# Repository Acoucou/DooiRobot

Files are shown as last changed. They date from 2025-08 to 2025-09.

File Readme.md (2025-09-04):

# DooiRobot

## 概述

该项目由doly魔改而来，3D模型做了适配，硬件以及软件为自制，采用聆思的CSK6；

请用 “嘿、dooi” 唤醒我

当前支持功能如下：

1、单轮多轮对话，打断唤醒

2、支持情绪理解，多种情感反馈（眼睛、led、舵机、电机的结合）

3、支持物体识别、拍照等

4、支持音乐播放

5、支持蓝牙配网，局域网web控制

6、

- [视频演示]()
- 

## 固件烧录

1、[下载烧录软件](https://docs2.listenai.com/zz/6941.exe?shortId=oo2_KzYFd)

2、将bin固件拖至软件

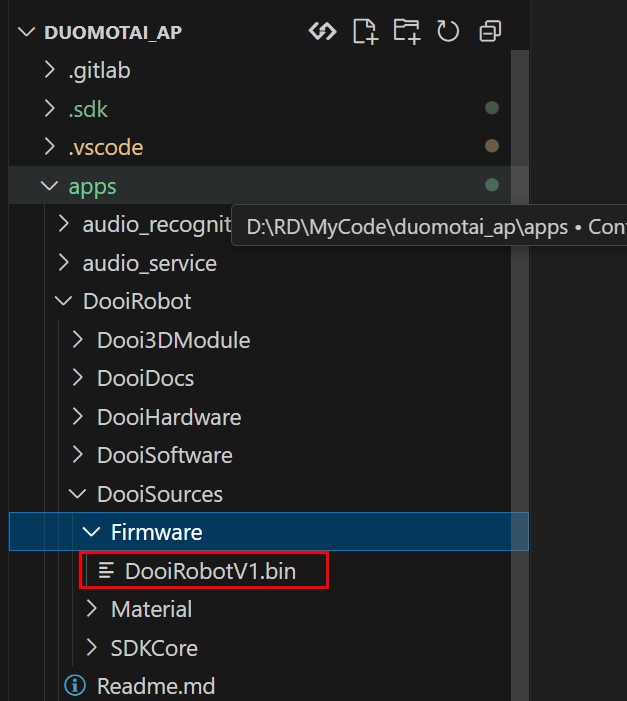
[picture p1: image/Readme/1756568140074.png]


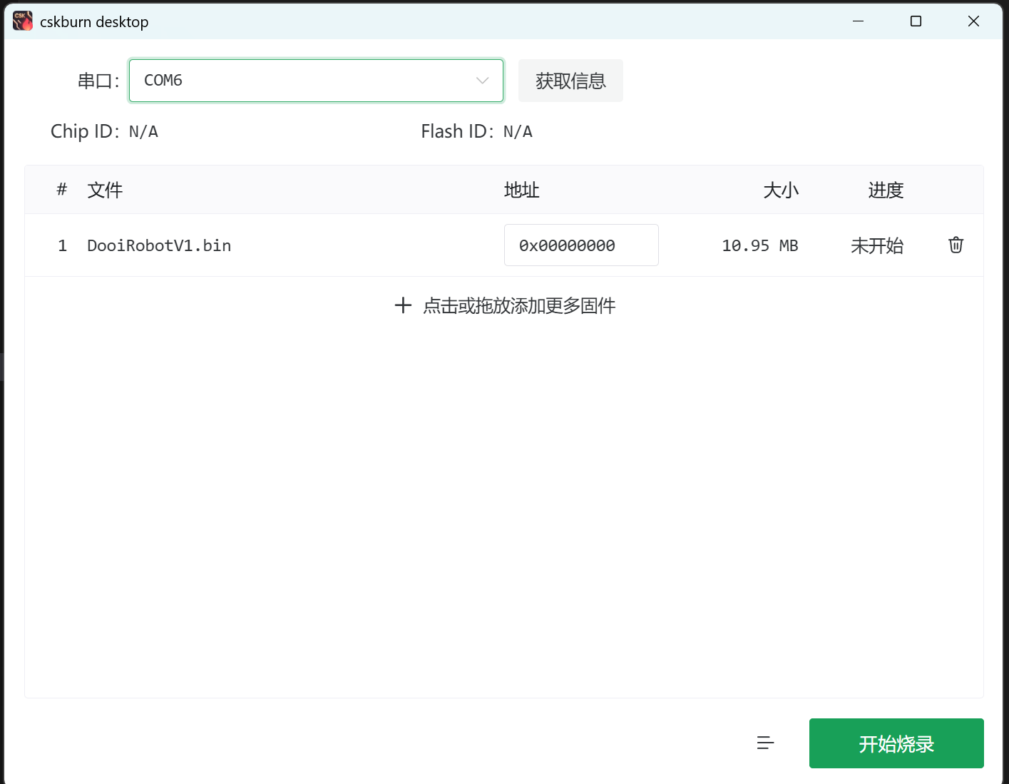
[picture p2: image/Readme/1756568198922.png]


3、点击烧录后，立刻点击开发版的boot按键，开始烧录

## 软件环境搭建

1、安装lisa环境及获取SDK：[参考文档](https://docs2.listenai.com/x/xfI6rkDCKmW)

2、获取项目

```
cd /duomotai_ap/apps
git clone https://github.com/Acoucou/DooiRobot.git
```

最终目录如下图，没有git也可以直接将下载下来的项目放置于apps目录下（主要是方便脚本执行）

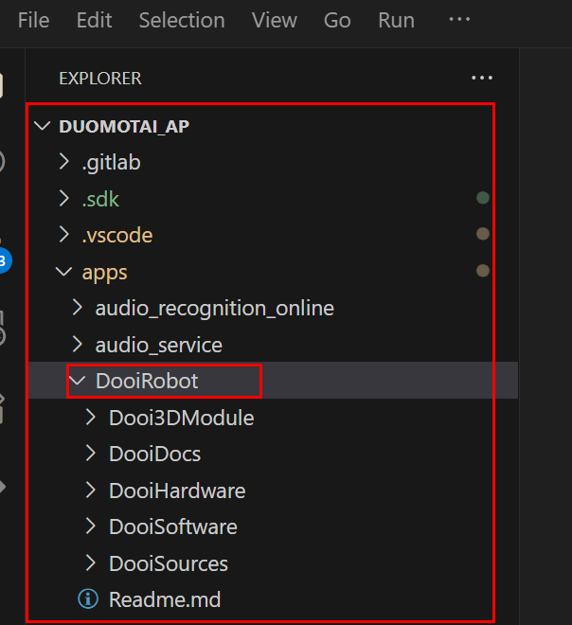
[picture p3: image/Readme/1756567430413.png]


3、执行拷贝脚本，拷贝文件到SDK

```
cd DooiRobot/DooiSources/SDKCore
./copy_shell.bat  			// 执行脚本
```

4、编译程序

```
cd duomotai_ap
lisa zep build -b csk6_dooi_robot_v1 .\apps\DooiRobot\DooiSoftware -p
```

5、烧录

```
lisa zep exec cskburn -s \\.\COM6 -C 6 -b 1500000 0x000000 .\build\zephyr\zephyr.bin  
```

## 平台

[aiui](https://aiui.xfyun.cn/user/login?pageFrom=https%3A%2F%2Faiui.xfyun.cn%2Fapp)

[聆思后台](https://platform.listenai.com/application)

[唤醒词替换文档](https://tool.listenai.com/audio-custom/products/)

[替换应答语](https://docs2.listenai.com/x/txcGbh4g-) ： lisa zep exec mklfs apps\LLM_pic\resource\tone\ littlefs.bin 0x100000

[应答音频合成](https://www.iflyos.cn/tts-file)

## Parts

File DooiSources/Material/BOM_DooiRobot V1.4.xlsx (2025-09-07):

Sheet: BOM_Dooi_CE_Head(2套)
序号 | 类型 | 型号 | 值 | 位号 | 封装 | 数量 | 立创编号 | 单价 | 总价
1 | 贴片电阻 | FRC0603F8R20TS | 3.9Ω | R23 | R0603 | 1 | C23020 | 0.0118 | 0.0118
2 | 贴片电阻 | 0603WAF1001T5E | 1kΩ | R17,R18 | R0603 | 2 | C21190 | 0.0065 | 0.013
3 | 贴片电阻 | FRC0603F6801TS | 6.8kΩ | R21,R22 | R0603 | 2 | C2907055 | 0.00549 | 0.01098
4 | 贴片电阻 | FRC0603J103 TS | 10kΩ | R1,R2,R13,R16 | R0603 | 4 | C2930027 | 0.0049 | 0.0196
5 | 贴片电阻 | FRC0603F1003TS | 100kΩ | R6 | R0603 | 1 | C2906980 | 0.0062 | 0.0062
6 | 贴片电阻 | FRC0603F3003TS | 300kΩ | R7 | R0603 | 1 | C2930091 | 0.0062 | 0.0062
7 | 贴片电阻 | FRL0805FR400TS | 400mΩ | R4,R5 | R0805 | 2 | C2934266 | 0.0286 | 0.0572
8 | 贴片电容(MLCC) | CL10B103KB8NNNC | 10nF/50V | C2 | C0603 | 1 | C1589 | 0.0195 | 0.0195
9 | 贴片电容(MLCC) | CL10B104KB8NNNC | 100nF/50V | C11,C13 | C0603 | 2 | C1591 | 0.0177 | 0.0354
10 | 贴片电容(MLCC) | CL10A225KP8NNNC | 2.2uF/10V | C1 | C0603 | 1 | C1607 | 0.0397 | 0.0397
11 | 贴片电容(MLCC) | CL10A106MO8NQNC | 10uF/16V | C3,C4,C10 | C0603 | 3 | C92487 | 0.0898 | 0.2694
12 | 贴片电容(MLCC) | CL10A226MO7JZNC | 22uF/10V | C5,C6,C15,C17 | C0603 | 4 | C86295 | 0.0885 | 0.354
13 | 功率电感 | FNR4030S3R3MT | 3.3uH | L1 | IND-SMD | 1 | C167870 | 0.315 | 0.315
14 | 肖特基二极管 | DSK24 |  | D1 | SOD-123FL | 1 | C22466352 | 0.132 | 0.132
15 | 触摸芯片 | AM01B |  | U7,U8 | SOT-23-6 | 2 | C485387 | 0.548 | 1.096
16 | LED驱动 | PCA9635PW,118 |  | U3 | TSSOP-28 | 1 |  | 1.94 | 1.94 | https://item.taobao.com/item.htm?abbucket=16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
17 | 步进电机驱动芯片 | DRV8833PWPR |  | U2 | TSSOP-16 | 1 |  | 0.97 | 0.97 | https://item.taobao.com/item.htm?id=743512094087&skuId=5129466113757
18 | DC-DC电源芯片 | ME2149FSG |  | U9 | SOP-8 | 1 | C236784 | 0.804 | 0.804
19 | LDO电源芯片 | XC6206P332MR-MS |  | U12,U13 | SOT-23 | 2 | C5252899 | 0.073435 | 0.14687
20 | 功率电子开关 | MT9700-N |  | U10,U11 | MT9700 | 2 | C42441843 | 0.2497 | 0.4994
21 | 线对板针座 | M1250VS-06P |  | CN2 | CONN-SMD-06P | 1 | C705224 | 0.48 | 0.48
22 | 线对板针座 | M1250VS-07P |  | CN1 | CONN-SMD-07P | 1 | C705225 | 0.541 | 0.541
23 | 线对板针座 | ZX-SH1.0-2PLT |  | CN7,CN8 | CONN-SMD_2P-P1.00 | 2 | C7430451 | 0.353 | 0.706
24 | 线对板针座 | ZX-SH1.0-3PLT |  | CN5,CN6,CN9 | CONN-SMD_3P-P1.00 | 3 | C7430452 | 0.394 | 1.182
25 | 模拟开关 | WAS3157B-6/TR |  | U1 | SOT-363 | 1 | C213161 | 0.426 | 0.426
26 | FFC/FPC连接器 | AFC01-S08FCA-00 |  | FPC3,FPC4 | FPC-SMD_P0.5 | 2 | C262657 | 0.755 | 1.51
27 | FFC/FPC连接器 | FPC-05FB-6PH20 |  | FPC2 | FPC-SMD_6P-P0.5 | 1 | C2856827 | 0.833 | 0.833
28 | FFC/FPC连接器 | FPC-05FB-20PH20 |  | FPC1 | FPC-SMD_20P-P0.5 | 1 | C2856830 | 0.97 | 0.97
29 | 1.28寸液晶 | LCD 1.28\" ips round |  | LCDL,LCDR | 12PIN 焊线 | 2 |  | 9.7 | 19.4 | https://item.taobao.com/item.htm?abbucket=16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
 |  |  |  |  |  |  |  |  | 32.78245

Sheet: BOM_Dooi_CE_Arm（4套）
序号 | 类型 | 型号 | 值 | 位号 | 封装 | 数量 | 立创编号 | 单价 | 总价
1 | 贴片电阻 | FRC0603F15R0TS | 15Ω | R1,R3 | R0603 | 2 | C2906996 | 0.0057 | 0.0114
2 | 贴片电阻 | FRC0603F66R5TS | 66.5Ω | R2 | R0603 | 1 | C5153978 | 0.0057 | 0.0057
3 | RGB LED | XL-5050RGBC |  | LED1 | SMD5050 | 1 | C2843868 | 0.27227 | 0.27227
4 | FFC/FPC连接器 | AFC01-S08FCA-00 |  | ARM | FPC-SMD_P0.5 | 1 | C262657 | 0.755 | 0.755
 |  |  |  |  |  |  |  |  | 1.04437

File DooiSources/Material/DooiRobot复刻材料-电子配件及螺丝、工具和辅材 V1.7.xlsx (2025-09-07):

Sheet: 电子配件
序号 | 名称 | 型号 | 数量 | 价格 | 说明 | 购买链接
1 | 主板 | CSK6011A-BOX-Lite | 1 | 169 | 成品 | https://item.taobao.com/item.htm?id=880555508886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
2 | 麦克风模块 | ECM | 1 | 10 | 成品 | https://item.taobao.com/item.htm?id=880555508886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
3 | 扩展板 | Dooi_CE_Head | 1 | 65 | 开源
4 | 灯板 | Dooi_Arm | 2 | 5 | 开源
5 | 舵机 | SG90 90度-180度通用 | 2 | 5.76 | 成品 | https://detail.tmall.com/item.htm?id=615181368748
6 | 直流电机 | n20减速电机 60转/分钟;6V | 2 | 8.5 | 成品 | https://item.taobao.com/item.htm?id=769096395403&sku_properties=1627207%3A229752325
7 | 摄像头 | 120度无畸变 | 1 | 8.63 | 成品 | https://item.taobao.com/item.htm?id=815635387088
8 | FPC软排线 | 6P;同向;0.5mm;10CM | 1 | 0.14 | 成品 | https://item.taobao.com/item.htm?id=549515372213&sku_properties=-1%3A-1%3B-2%3A-2
9 | FPC软排线 | 8P;同向;0.5mm;15CM | 2 | 0.18 | 成品 | https://item.taobao.com/item.htm?id=549590794021&skuId=3342591461731
10 | FPC软排线 | 20P;同向;0．5mm;10CM | 1 | 0.2 | 成品 | https://item.taobao.com/item.htm?abbucket=16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
11 | FPC软排线 | 24P;同向;0．5mm;10CM | 1 | 0.22 | 成品 | https://item.taobao.com/item.htm?id=549658195046&sku_properties=-1%3A-1
12 | 端子线 | 6P;80mm;双头（反向） | 1 | 0.28 | 成品 | https://item.taobao.com/item.htm?id=607231799768
13 | 端子线 | 7P;80mm;双头（反向） | 1 | 0.33 | 成品 | https://item.taobao.com/item.htm?id=607231799768&skuId=4428270123207
14 | 端子线 | SH1.0/3P/10CM双头 | 1 | 0.36 | 成品 | https://item.taobao.com/item.htm?id=565360096163
15 | 端子线 | 3Pin;100mm绞线;双头（反向） | 1 | 1.66 | 成品 | https://item.taobao.com/item.htm?id=651242539508
16 | 端子线 | 0.1m;2P-单头线-SH1.0 | 3 | 0.36 | 成品 | https://detail.tmall.com/item.htm?id=729279056044
17 | 端子线 | 0.1m;3P-单头线-SH1.0 | 2 | 0.36 | 成品 | https://detail.tmall.com/item.htm?id=729279056044&sku_properties=1627207%3A26137369188
18 | 端子线 | 0.1m;间距1.25MM 4P 公转母 | 1 | 0.69 | 成品 | https://detail.tmall.com/item.htm?id=576790821801
19 | 定制铜片 | 0.2mm*10mm*40mm（厚度*宽度*长度） | 2 | 0.3 | 定制 | https://item.taobao.com/item.htm?id=809164757861&skuId=5539545328566
20 | 喇叭 | XHXDZ-2828-4R3W-2P1.25银色 | 1 | 5.5 | 成品 | https://item.taobao.com/item.htm?id=857879179989
21 | 电池 | 18650 3.7v 3000mAh ph2.0头B序[红黑B序] | 1 | 17.9 | 成品 | https://item.taobao.com/item.htm?id=653232266680
22 | TYPE-C公头 | 16P带板 4芯[长度9.5] | 1 | 0.92 | 成品 | https://item.taobao.com/item.htm?id=776314096149
23 | TYPE-C母座 | 16P母头转2.54 | 1 | 0.92 | 成品 | https://item.taobao.com/item.htm?id=645766200920
24 | 滑动开关 | 柄长L=4MM 黑色 | 1 | 0.39 | 成品 | https://item.taobao.com/item.htm?id=599886123444&skuId=5077133507056
25 | 咪头套 | 6022咪头套 | 1 | 0.1 | 成品 | https://item.taobao.com/item.htm?id=41991370377&skuId=5189735582995

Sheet: 螺丝和金属配件
序号 | 类型 | 安装位置 | 规格 | 数量 | 说明 | 链接
1 | 自攻螺丝 | 固定前壳到车架 固定侧边护板壳到车架 固定底盖到车架 固定支架到车架 固定舵机臂到手臂 固定手臂盖到手臂 | M2x5沉头自攻 | 15 |  | https://detail.tmall.com/item.htm?abbucket=16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
2 | 自攻螺丝 | 固定底盖到车架 | M2x16沉头自攻 | 2 |  | https://detail.tmall.com/item.htm?abbucket=16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
3 | 自攻螺丝 | 固定手臂到舵机 | M2x16圆头自攻 | 2 |  | https://item.taobao.com/item.htm?id=591339124515
4 | 自攻螺丝 | 固定头盖到前壳 | M2x8圆头自攻 | 1 |  | https://item.taobao.com/item.htm?id=591339124515
5 | 螺丝 | 固定直流电机到车架 | M1.6x3沉头 | 4 |  | https://item.taobao.com/item.htm?id=591244120254
6 | 自攻螺丝 | 固定电路板到车架 | M1.6x5圆头自攻 | 2 |  | https://detail.tmall.com/item.htm?abbucket=16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
7 | 自攻螺丝 | 固定喇叭到车架 | M3x6圆头自攻 | 4 |  | https://detail.tmall.com/item.htm?abbucket=16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
8 | 金属垫片 | 轮子与壳体之间 | M4x8x0.5 | 4 |  | https://item.taobao.com/item.htm?abbucket=16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
9 | 磁铁 | RGB灯罩圆孔内 | 直径5mm*厚2mm | 2 |  | https://detail.tmall.com/item.htm?id=618325891979

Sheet: 工具和辅材
序号 | 名称 | 型号 | 用途
1 | 电烙铁 |  | 直流电机和舵机重新焊接端子线
2 | 焊锡丝
3 | 热缩管 | 直径1mm | 套在焊接的端子上起绝缘保护作用
4 | 螺丝刀 | 十字、2.0 | 拧螺丝
5 | 剪刀
6 | 胶水 | 瞬干胶 | 部分零件需要用胶水粘接
7 | 电子胶 | K-200R红胶 | 固定部分焊线
8 | 打火机 |  | 用于加热热缩管

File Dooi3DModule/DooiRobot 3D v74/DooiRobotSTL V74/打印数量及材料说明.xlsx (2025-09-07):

名称 | 数量 | 材料 | 精度 | 备注
FDM_ARM_L | 2
FDM_ARM_LID_L | 2
FDM_arm_limiter_L | 1
FDM_arm_limiter_R | 1
FDM_block1 | 4
FDM_body_head | 1
FDM_body_main | 1
FDM_bottom_lid | 1
FDM_bumper_back | 1
FDM_bumper_front | 1
FDM_io_lid | 1
FDM_spacer_lid | 1
FDM_track_cover_L | 1
FDM_track_cover_R | 1
FDM_track_TPU | 2 | TPU |  | 需要橡胶材料
FDM_wheel_back_L | 2
FDM_wheel_front_L | 2
SLA_HAND_L | 1
SLA_HAND_R | 1
SLA_SERVO_ARM_L | 1 |  | 0.1mm
SLA_SERVO_ARM_R | 1 |  | 0.1mm

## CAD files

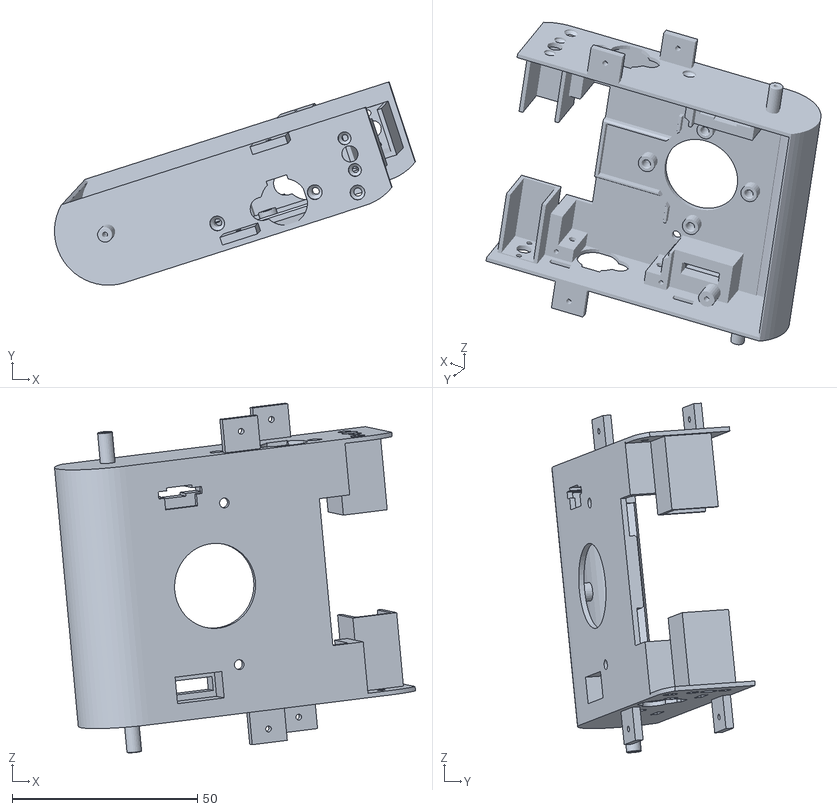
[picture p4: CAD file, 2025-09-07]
Dooi3DModule/DooiRobot 3D v74/DooiRobotSTL V74/FDM_body_main.stl
97.3 x 54.8 x 94.3

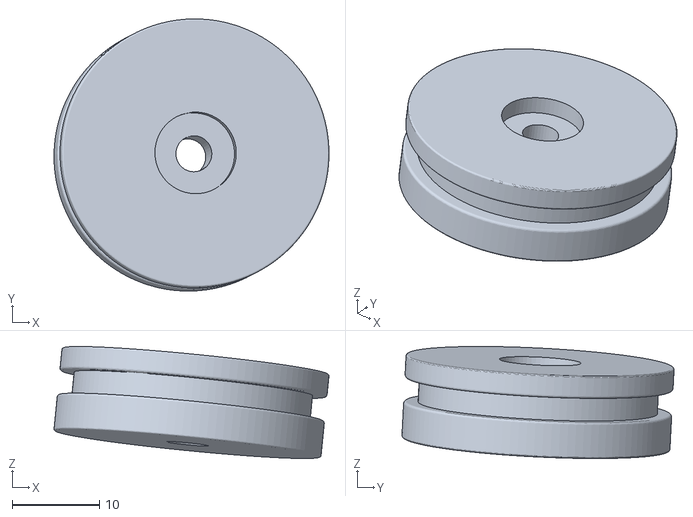
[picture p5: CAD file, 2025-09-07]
Dooi3DModule/DooiRobot 3D v74/DooiRobotSTL V74/FDM_wheel_back_L.stl
31.4 x 31.1 x 12.8

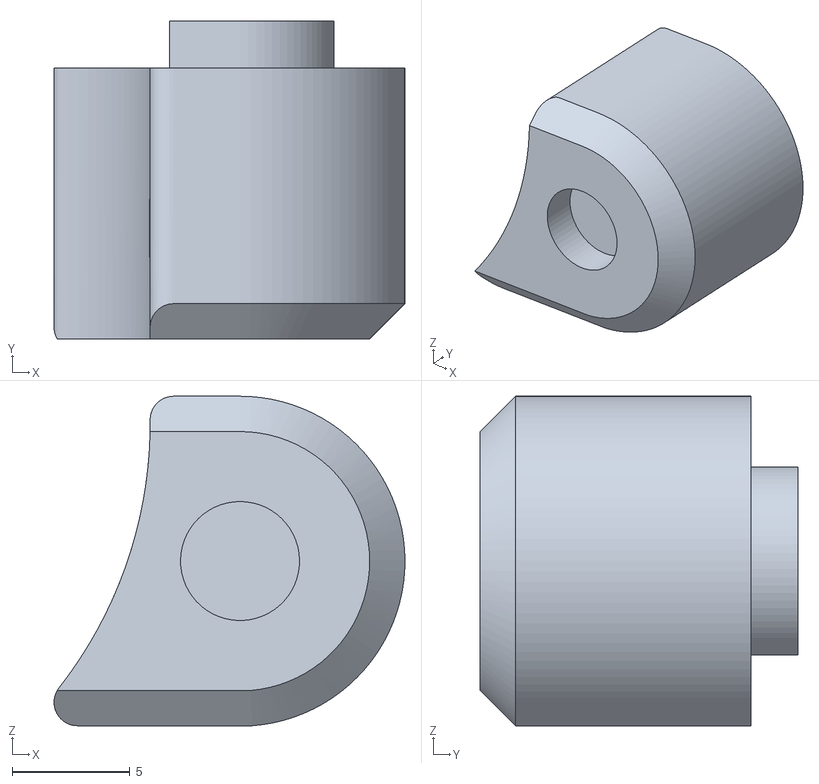
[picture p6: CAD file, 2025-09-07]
Dooi3DModule/DooiRobot 3D v74/DooiRobotSTL V74/SLA_HAND_L.stl
14.9 x 13.5 x 14.0

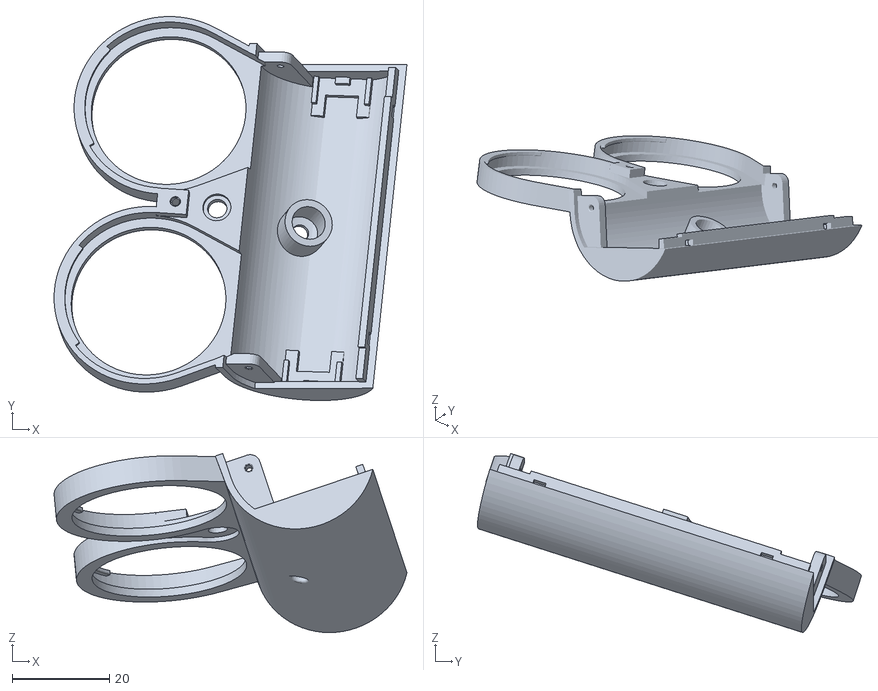
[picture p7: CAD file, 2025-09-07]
Dooi3DModule/DooiRobot 3D v74/DooiRobotSTL V74/FDM_bumper_front.stl
72.7 x 79.1 x 36.9

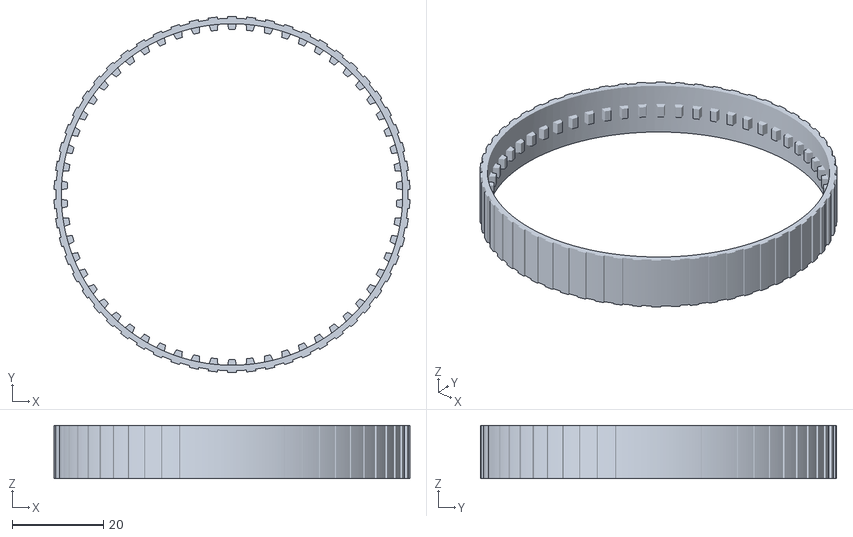
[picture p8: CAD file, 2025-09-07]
Dooi3DModule/DooiRobot 3D v74/DooiRobotSTL V74/FDM_track_TPU.stl
78.2 x 78.2 x 11.7

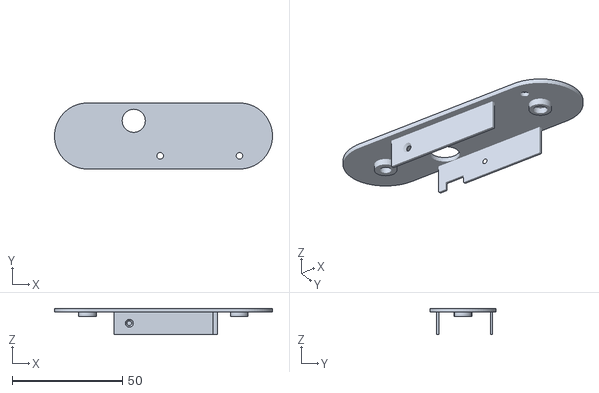
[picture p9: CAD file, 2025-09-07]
Dooi3DModule/DooiRobot 3D v74/DooiRobotSTL V74/FDM_track_cover_L.stl
99.0 x 30.0 x 12.0

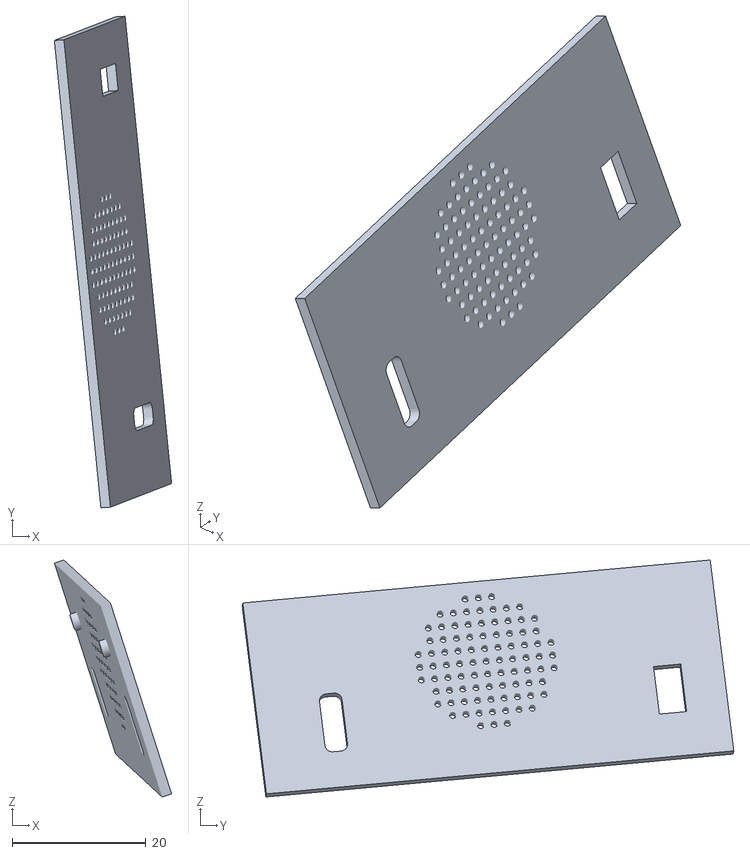
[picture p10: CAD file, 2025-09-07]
Dooi3DModule/DooiRobot 3D v74/DooiRobotSTL V74/FDM_io_lid.stl
17.5 x 73.4 x 35.4

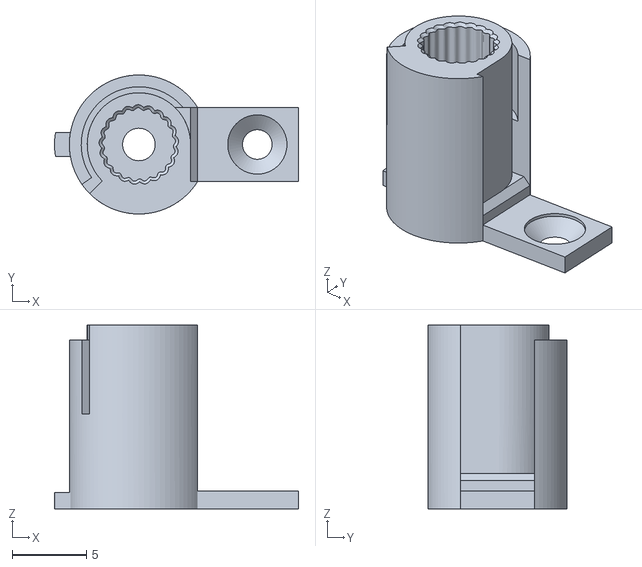
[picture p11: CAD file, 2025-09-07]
Dooi3DModule/DooiRobot 3D v74/DooiRobotSTL V74/SLA_SERVO_ARM_L.stl
16.5 x 9.39 x 12.4

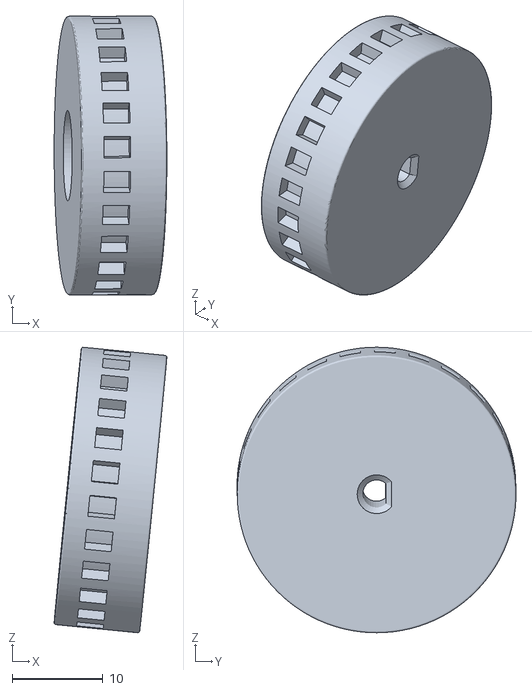
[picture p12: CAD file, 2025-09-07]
Dooi3DModule/DooiRobot 3D v74/DooiRobotSTL V74/FDM_wheel_front_L.stl
12.5 x 30.8 x 31.5

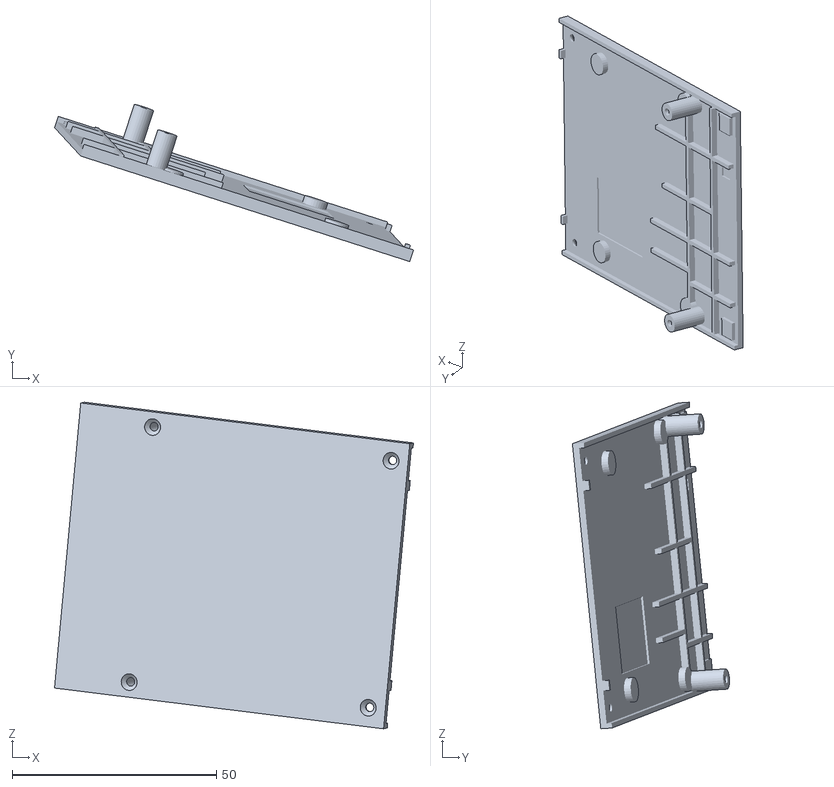
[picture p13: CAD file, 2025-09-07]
Dooi3DModule/DooiRobot 3D v74/DooiRobotSTL V74/FDM_bottom_lid.stl
87.9 x 38.5 x 79.9

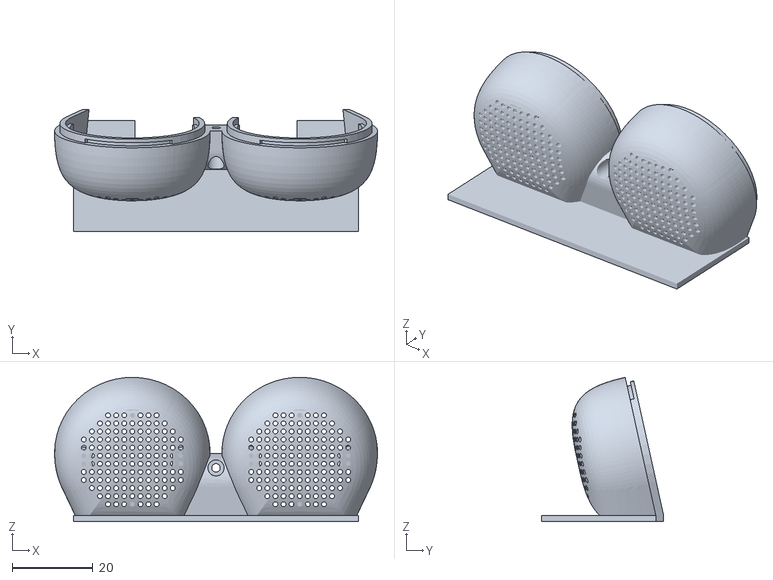
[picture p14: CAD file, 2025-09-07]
Dooi3DModule/DooiRobot 3D v74/DooiRobotSTL V74/FDM_body_head.stl
79.9 x 30.3 x 35.7

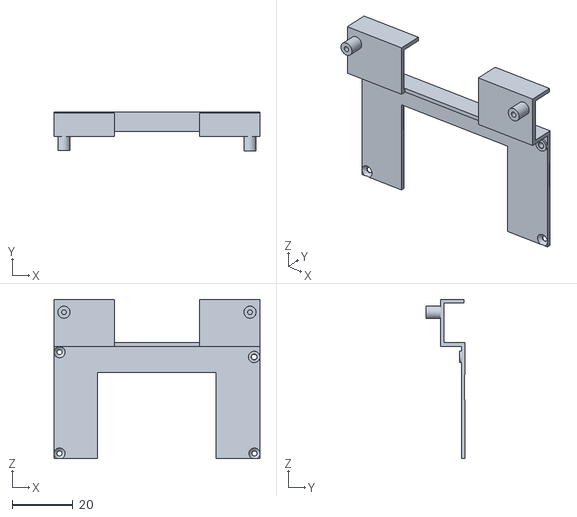
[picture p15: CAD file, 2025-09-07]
Dooi3DModule/DooiRobot 3D v74/DooiRobotSTL V74/FDM_spacer_lid.stl
67.6 x 12.8 x 52.2

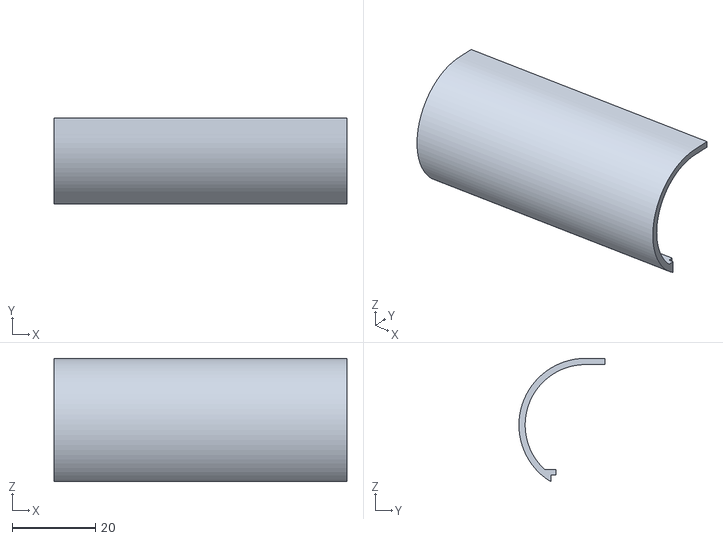
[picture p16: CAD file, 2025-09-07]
Dooi3DModule/DooiRobot 3D v74/DooiRobotSTL V74/FDM_bumper_back.stl
70.4 x 20.7 x 29.6

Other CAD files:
Dooi3DModule/DooiRobot 3D v74/DooiRobotSTL V74/SLA_HAND_R.stl
Dooi3DModule/DooiRobot 3D v74/DooiRobotSTL V74/SLA_SERVO_ARM_R.stl
Dooi3DModule/DooiRobot 3D v74/DooiRobotSTL V74/FDM_track_cover_R.stl

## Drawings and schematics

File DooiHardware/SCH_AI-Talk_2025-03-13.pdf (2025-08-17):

V1.0 | First Edit | 20240501 | caiyong

# Author

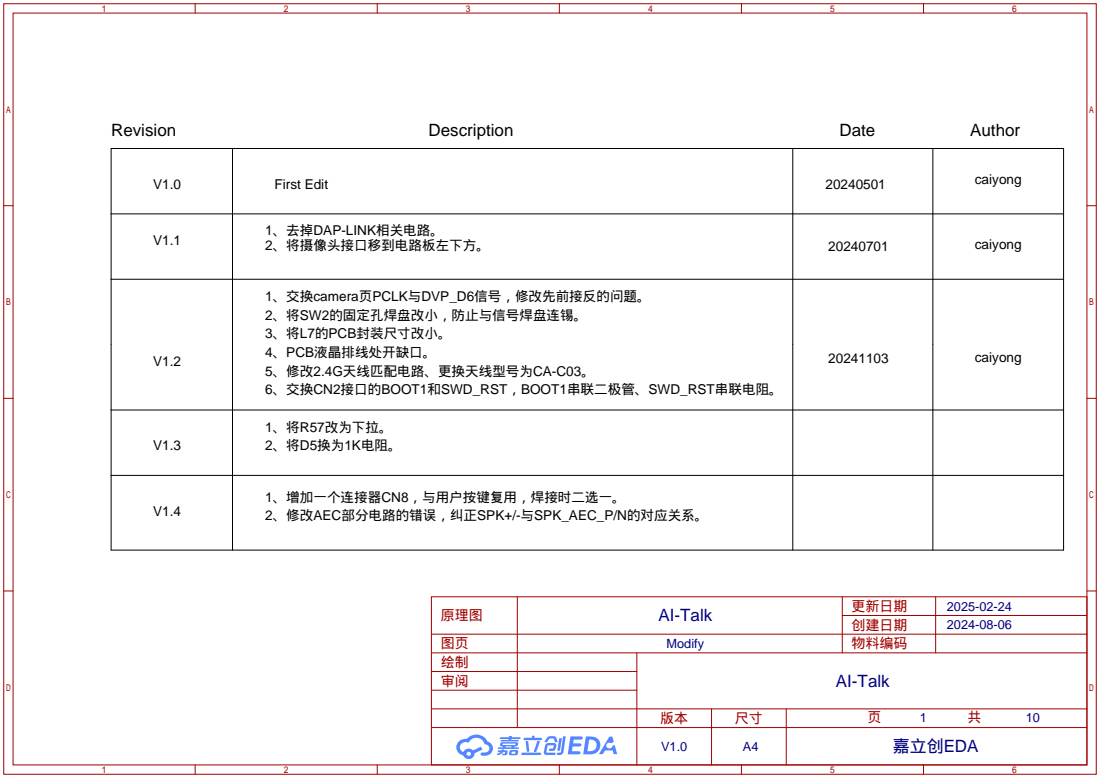
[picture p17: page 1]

V1.1 | 1、去掉DAP-LINK相关电路。 2、将摄像头接口移到电路板左下方。 | 20240701 | caiyong

V1.2 | 1、交换camera页PCLK与DVP_D6信号，修改先前接反的问题。 2、将SW2的固定孔焊盘改小，防止与信号焊盘连锡。 3、将L7的PCB封装尺寸改小。 4、PCB液晶排线处开缺口。 5、修改2.4G天线匹配电路、更换天线型号为CA-C03。 6、交换CN2接口的BOOT1和SWD_RST，BOOT1串联二极管、SWD_RST串联电阻。 | 20241103 | caiyong

V1.3 | 1、将R57改为下拉。 2、将D5换为1K电阻。

V1.4 | 1、增加一个连接器CN8，与用户按键复用，焊接时二选一。 2、修改AEC部分电路的错误，纠正SPK+/-与SPK_AEC_P/N的对应关系。

# SPI0

# WIFI

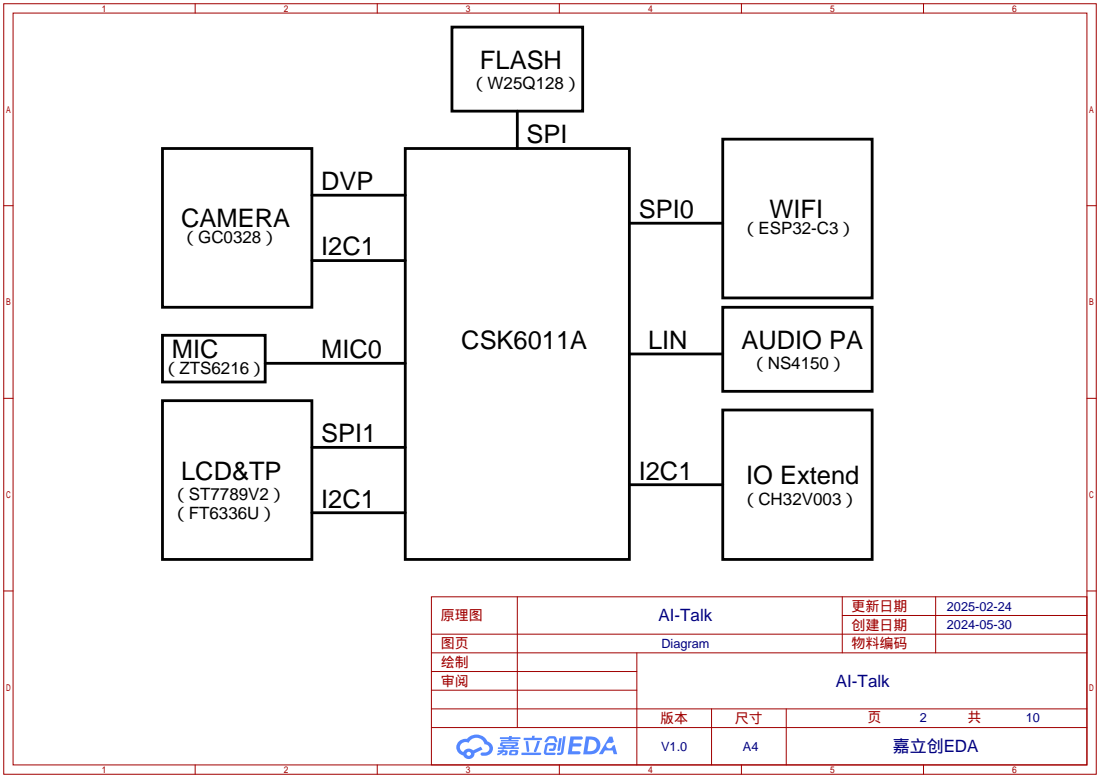
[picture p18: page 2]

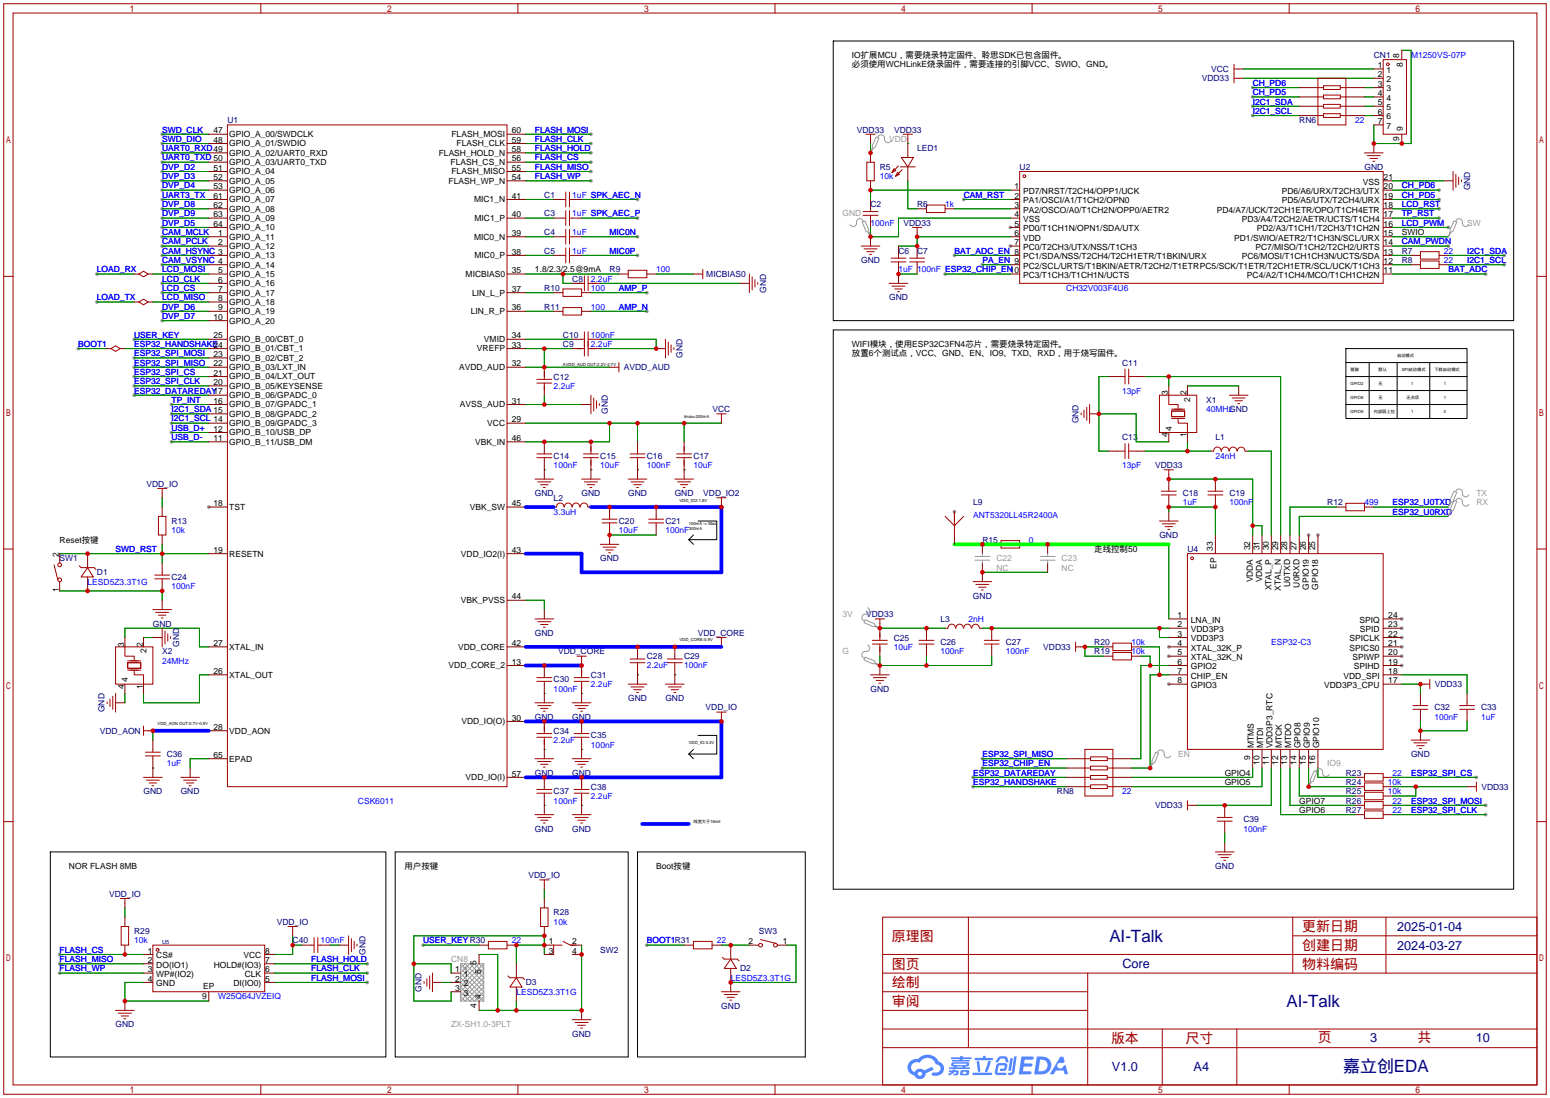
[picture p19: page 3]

IO扩展MCU，需要烧录特定固件、聆思SDK已包含固件。
必须使用WCHLinkE烧录固件，需要连接的引脚VCC、SWIO、GND。

WIFI模块，使用ESP32C3FN4芯片，需要烧录特定固件。
放置6个测试点，VCC、GND、EN、IO9、TXD、RXD，用于烧写固件。

管脚 | 默认 | SPI启动模式 | 下载启动模式

GPIO2 | 无 | 1 | 1

GPIO8 | 无 | 无关项 | 1

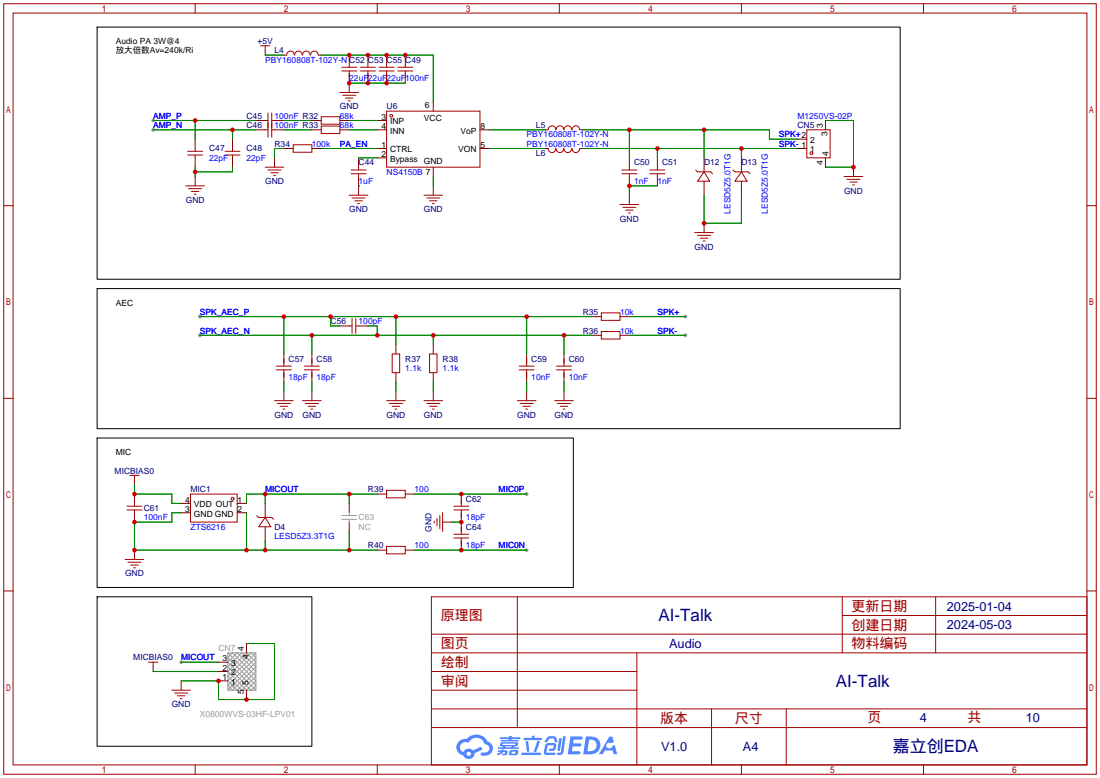
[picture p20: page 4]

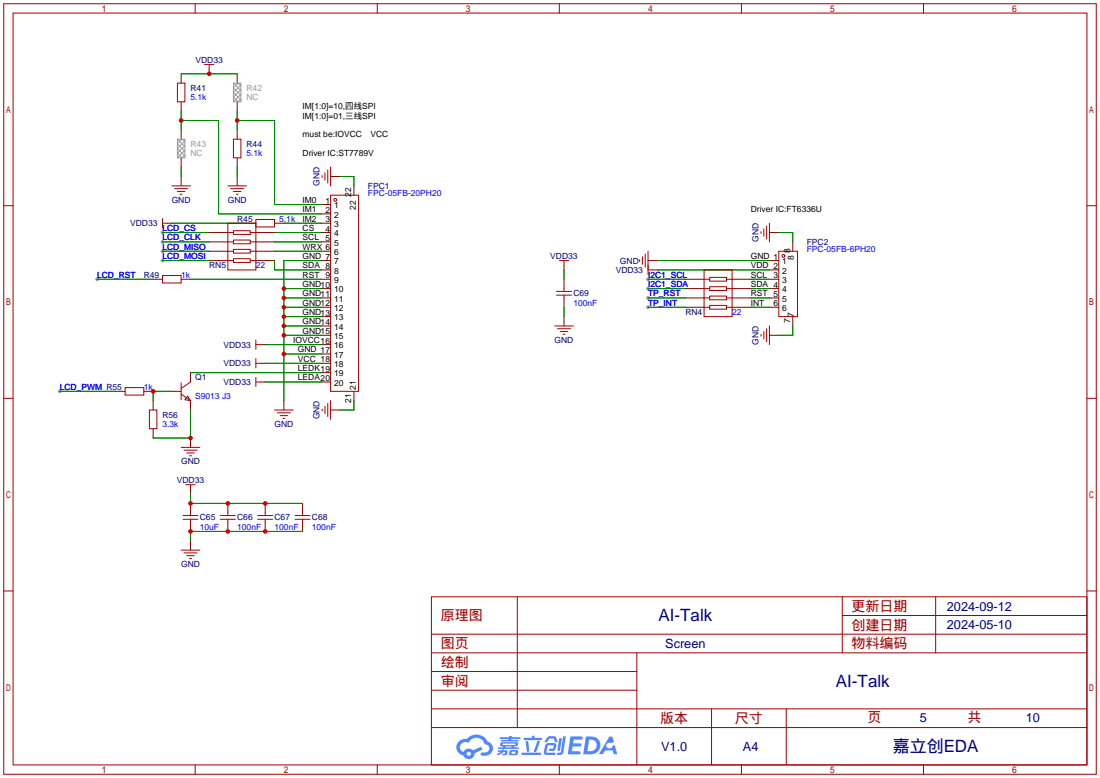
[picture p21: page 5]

IM[1:0]=10,四线SPI
IM[1:0]=01,三线SPI
must be:IOVCC VCC
Driver IC:ST7789V

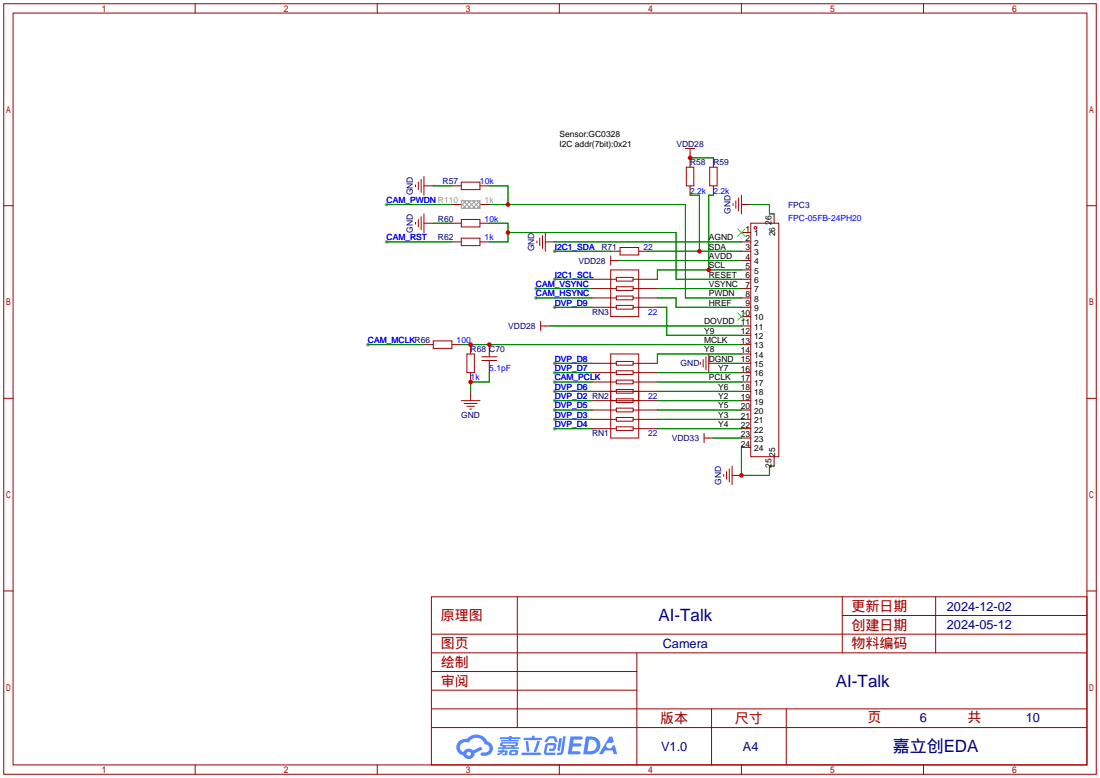
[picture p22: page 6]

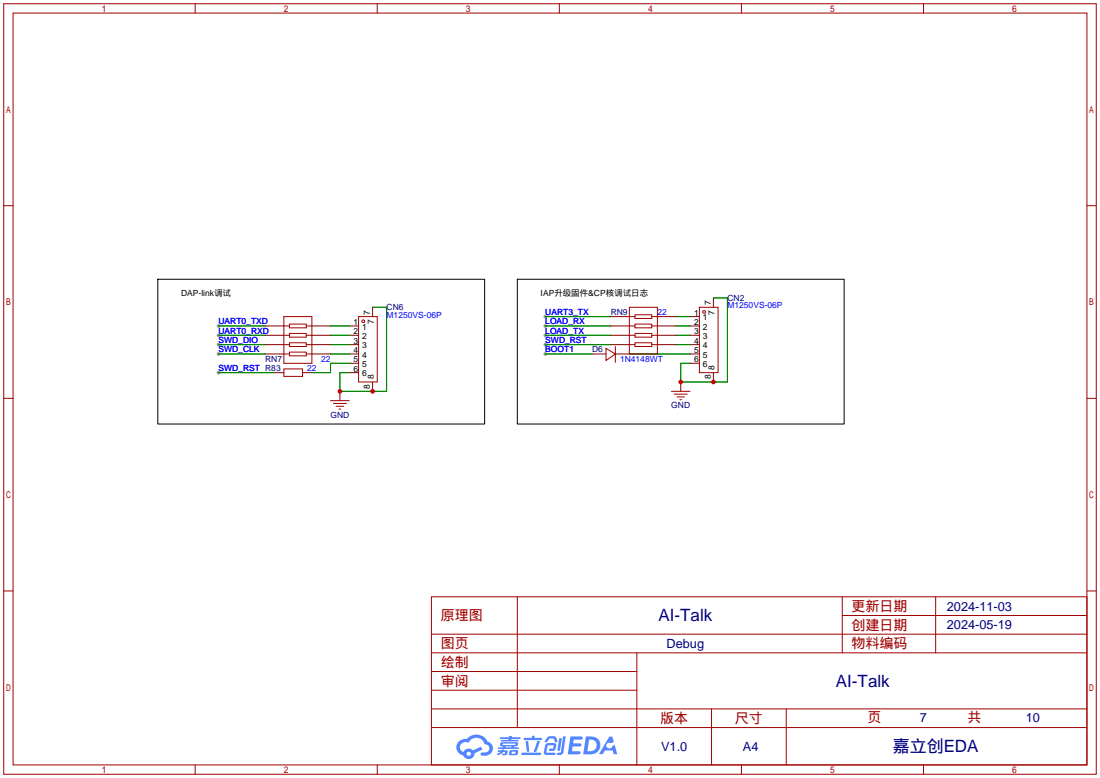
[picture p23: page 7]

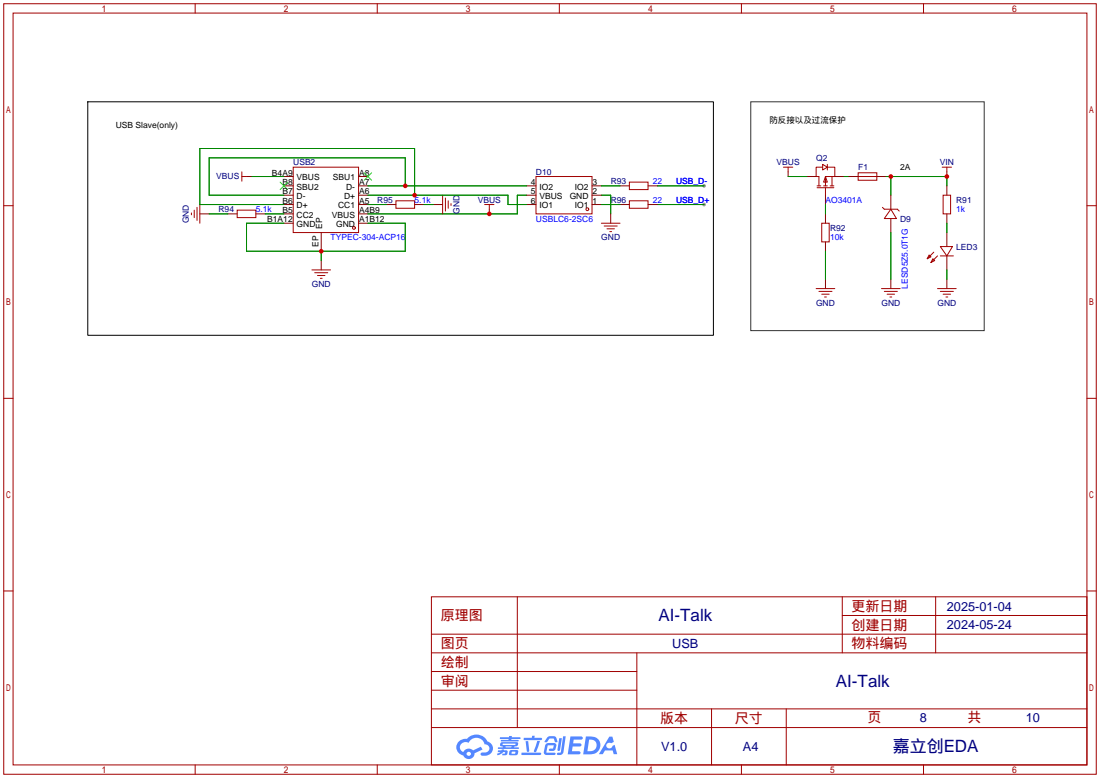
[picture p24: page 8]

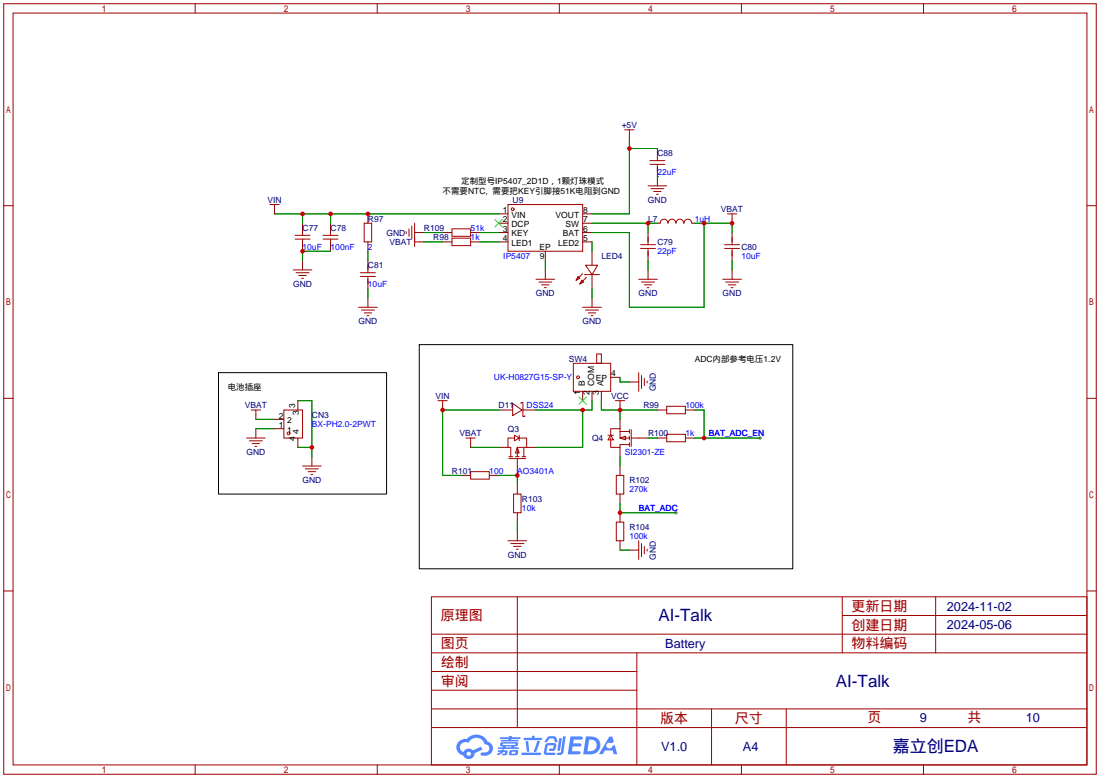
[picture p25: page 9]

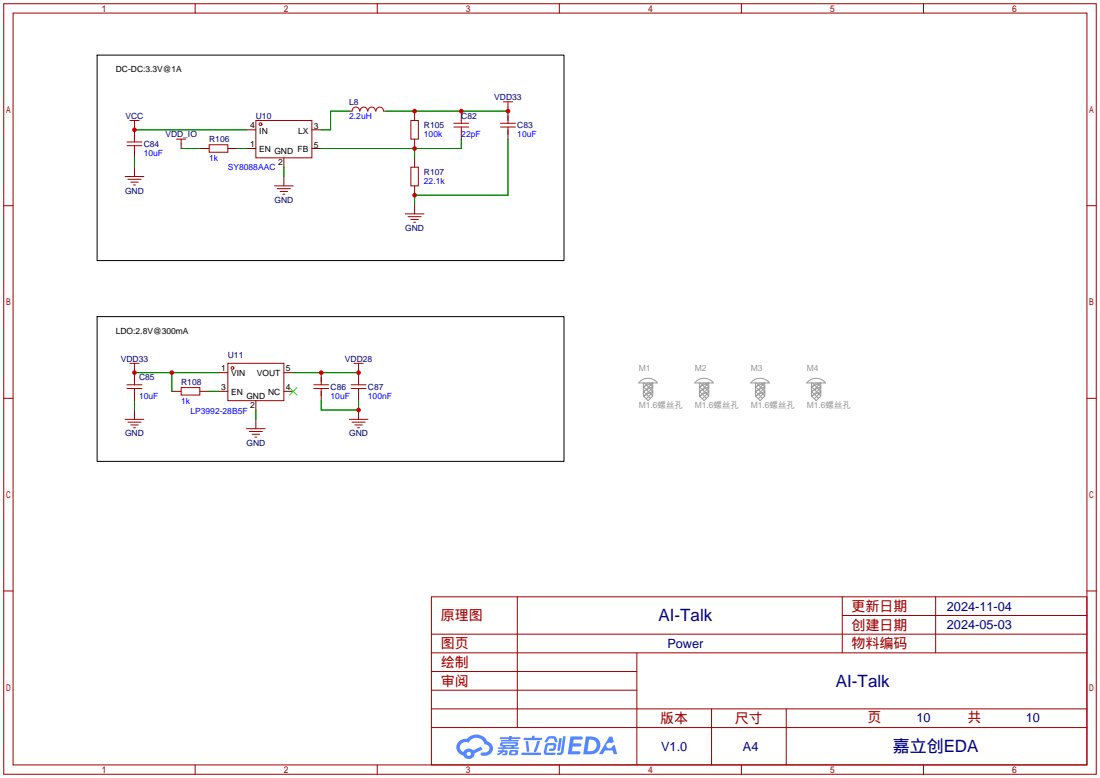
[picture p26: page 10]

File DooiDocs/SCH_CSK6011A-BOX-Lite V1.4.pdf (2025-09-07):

V1.0 | First Edit | 20240501 | caiyong
V1.1 | 1、去掉DAP-LINK相关电路。 2、将摄像头接口移到电路板左下方。 | 20240701 | caiyong

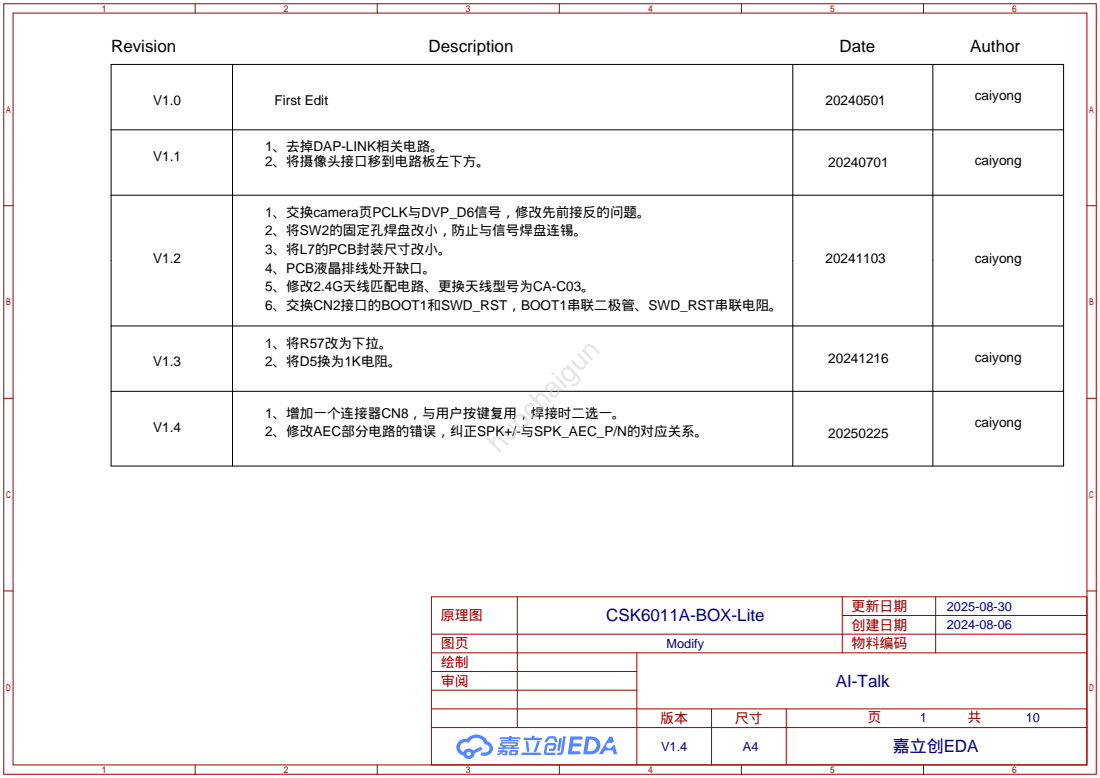
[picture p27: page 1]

V1.2 | 1、交换camera页PCLK与DVP_D6信号，修改先前接反的问题。 2、将SW2的固定孔焊盘改小，防止与信号焊盘连锡。 3、将L7的PCB封装尺寸改小。 4、PCB液晶排线处开缺口。 5、修改2.4G天线匹配电路、更换天线型号为CA-C03。 6、交换CN2接口的BOOT1和SWD_RST，BOOT1串联二极管、SWD_RST串联电阻。 | 20241103 | caiyong

V1.3 | 1、将R57改为下拉。 2、将D5换为1K电阻。 | 20241216 | caiyong huochaigun

V1.4 | 1、增加一个连接器CN8，与用户按键复用，焊接时二选一。 2、修改AEC部分电路的错误，纠正SPK+/-与SPK_AEC_P/N的对应关系。 | 20250225 | caiyong

# SPI0

# WIFI

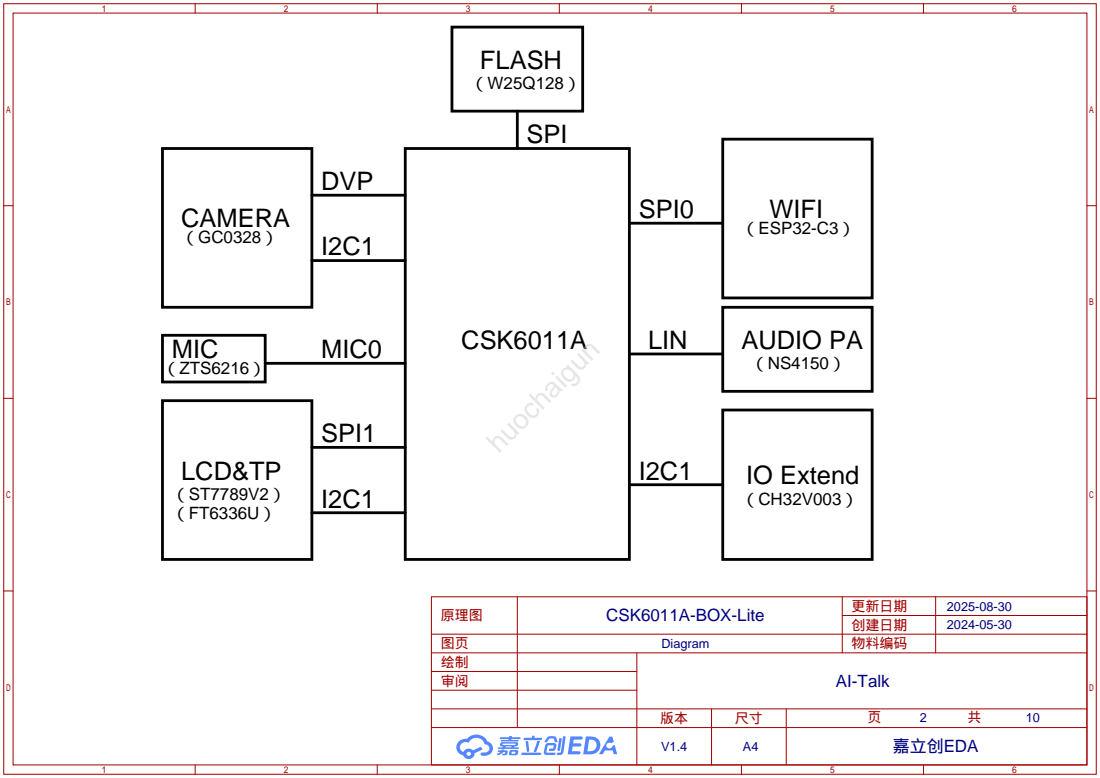
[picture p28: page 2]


IO扩展MCU，需要烧录特定固件、聆思SDK已包含固件。
必须使用WCHLinkE烧录固件，需要连接的引脚VCC、SWIO、GND。

WIFI模块，使用ESP32C3FN4芯片，需要烧录特定固件。
放置6个测试点，VCC、GND、EN、IO9、TXD、RXD，用于烧写固件。

管脚 | 默认 | SPI启动模式 | 下载启动模式

GPIO2 | 无 | 1 | 1

GPIO8 | 无 | 无关项 | 1



IM[1:0]=10,四线SPI
IM[1:0]=01,三线SPI
must be:IOVCC VCC
Driver IC:ST7789V






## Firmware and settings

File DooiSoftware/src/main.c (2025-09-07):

#include <zephyr/kernel.h>
#include <zephyr/devicetree.h>
#include <zephyr/storage/flash_map.h>
#include "boot_cp.h"
#include "ic_message.h"
#include <stdint.h>
#include <stddef.h>
#include <time.h>
#include "resource.h"
#include "app_player.h"
#include "app_connect.h"
#include "app_chat.h"
#include "app_chat_wakeup.h"
#include <zephyr/logging/log.h>
LOG_MODULE_REGISTER(main, LOG_LEVEL_INF);


#define CP_FLASH_BASE_ADDRESS (0x68000000)
#define FLASH_CP_IMAGE_REGION_OFFSET DT_REG_ADDR(DT_NODE_BY_FIXED_PARTITION_LABEL(cp_code))
#define CP_BOOT_ADDRESS (CP_FLASH_BASE_ADDRESS + FLASH_CP_IMAGE_REGION_OFFSET)

#define MAX_PLAYER_NUMS 3
player_focus_action_e ops_table[MAX_PLAYER_NUMS][MAX_PLAYER_NUMS] = {
		/*                   TONE_PLAYER                   TTS_PLAYER          MUSIC_PLAYER*/
		/*TONE_PLAYER*/ {PLAYER_FOCUS_CANCELED, PLAYER_FOCUS_CANCELED, PLAYER_FOCUS_PAUSED},
		/*TTS_PLAYER*/ {PLAYER_FOCUS_BACKOFF, PLAYER_FOCUS_CANCELED, PLAYER_FOCUS_PAUSED},
		/*MUSIC_PLAYER*/ {PLAYER_FOCUS_BACKOFF, PLAYER_FOCUS_QUEUED, PLAYER_FOCUS_CANCELED},
};

int main(void)
{
	boot_cp((const void *)CP_BOOT_ADDRESS);
#if (CONFIG_WAKEUP_DEBUG)
	extern void usb_cdc_acm_init(void);
	usb_cdc_acm_init();
#endif
	ic_message_init();
#if (CONFIG_GCL_COMP_RES)
	components_resource_load();
#endif

	srand((unsigned)time(NULL));
	
	extern void ble_connect_task_init();
	ble_connect_task_init();

	extern int camera_init(void);
	camera_init();

	app_player_config_t config = {
			.focus_config =
					{
							.focus_table = (player_focus_action_e *)ops_table,
							.row_column_num = MAX_PLAYER_NUMS,
					},
			.app_player_num = MAX_PLAYER_NUMS,
	};
	app_player_init(&config);

	app_chat_wakeup_init();

	app_connect_init();

	app_chat_init();
}

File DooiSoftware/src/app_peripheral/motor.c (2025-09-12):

#include <zephyr/device.h>
#include <zephyr/drivers/i2c.h>
#include <zephyr/drivers/gpio.h>
#include <zephyr/kernel.h>
#include <stdint.h>
#include <math.h>
#include "motor.h"
#include "pca9635.h"

#include <zephyr/logging/log.h>
LOG_MODULE_REGISTER(motor, LOG_LEVEL_INF);

static motor_ctrl_t m_motor;
uint8_t dir_left_trun = 0;
uint8_t dir_right_trun = 0;

#define GPIOA_2_NODE DT_ALIAS(gpioa2)
static const struct gpio_dt_spec gpioa2 = GPIO_DT_SPEC_GET(GPIOA_2_NODE, gpios);

void motor_wakeup()
{
    gpio_pin_set_dt(&gpioa2, 1);
}

void motor_sleep()
{
    gpio_pin_set_dt(&gpioa2, 0);
}

/* 生成S曲线加速表 */
static void generate_accel_table(void) {
    const float factor = 2 * 3.14159f / MOTOR_ACCEL_STEPS;
    for (int i = 0; i < MOTOR_ACCEL_STEPS; i++) {
        float ratio = (1 - cosf(i * factor)) / 2;
        m_motor.accel_table[i] = (uint32_t)(ratio * 1000);
    }
}

/* 驱动电机硬件 */
static void drive_motors(int16_t left, int16_t right) {
    uint8_t buff[2] = {0};

    if(dir_left_trun)
    {
        left *= -1;
    }
    if(dir_right_trun)
    {
        right *= -1;
    }

    /* 左电机控制 */
    if (left >= 0) {
        // pca9635_set_pwm(MOTOR_LEFT_CHANNEL_A, (left * 255) / 100);
        // pca9635_set_pwm(MOTOR_LEFT_CHANNEL_B, 0);

        buff[0] = (left * 255) / 100;
        buff[1] = 0;

        pca9635_set_pwms(0xAC, buff, 2);
    } else {
        // pca9635_set_pwm(MOTOR_LEFT_CHANNEL_A, 0);
        // pca9635_set_pwm(MOTOR_LEFT_CHANNEL_B,
        buff[0] = 0;
        buff[1] = (-left * 255) / 100;

        pca9635_set_pwms(0xAC, buff, 2);
    }

    /* 右电机控制 */
    if (right >= 0) {
        // pca9635_set_pwm(MOTOR_RIGHT_CHANNEL_A, (right * 255) / 100);
        // pca9635_set_pwm(MOTOR_RIGHT_CHANNEL_B, 0);
        buff[0] = (right * 255) / 100;
        buff[1] = 0;

        pca9635_set_pwms(0xAE, buff, 2);
    } else {
        // pca9635_set_pwm(MOTOR_RIGHT_CHANNEL_A, 0);
        // pca9635_set_pwm(MOTOR_RIGHT_CHANNEL_B, (-right * 255) / 100);
        buff[0] = 0;
        buff[1] = (-right * 255) / 100;

        pca9635_set_pwms(0xAE, buff, 2);
    }

    LOG_DBG("Motors set to L:%d R:%d", left, right);
}

/* 计算当前速度(带S曲线加速) */
static void calculate_speed(void) {
    uint32_t now = k_uptime_get();
    
    // 检查是否到达更新时间
    if (now - m_motor.last_update < MOTOR_UPDATE_INTERVAL) {
        return;
    }
    m_motor.last_update = now;

    // 确保有足够的步骤
    if (m_motor.step_total == 0) {
        LOG_ERR("Invalid step_total: 0");
        m_motor.state = MOTOR_STATE_IDLE;
        return;
    }

    /* 修复1: 检测方向变化并重置加速曲线 */
    bool direction_changed = 
        (m_motor.target_left * m_motor.current_left < 0) || 
        (m_motor.target_right * m_motor.current_right < 0);
    
    if (direction_changed) {
        // 方向改变时重置加速曲线
        m_motor.current_left = 0;
        m_motor.current_right = 0;
        m_motor.step_index = 0;
        LOG_DBG("Direction change detected, resetting acceleration");
    }

    /* 计算加速比例 */
    uint32_t progress = (m_motor.step_index * 1000) / m_motor.step_total;
    uint32_t accel_step = (progress * MOTOR_ACCEL_STEPS) / 1000;
    accel_step = MIN(accel_step, MOTOR_ACCEL_STEPS - 1);
    float accel_ratio = m_motor.accel_table[accel_step] / 1000.0f;

    /* 应用加速曲线 */
    int16_t delta_left = m_motor.target_left - m_motor.current_left;
    int16_t delta_right = m_motor.target_right - m_motor.current_right;
    
    /* 修复2: 方向改变时使用更快的加速曲线 */
    if (direction_changed) {
        // 方向改变时使用线性加速，跳过S曲线
        float linear_ratio = (float)(m_motor.step_index + 1) / m_motor.step_total;
        m_motor.current_left = m_motor.current_left + (int16_t)(delta_left * linear_ratio);
        m_motor.current_right = m_motor.current_right + (int16_t)(delta_right * linear_ratio);
    } else {
        // 正常情况使用S曲线加速
        m_motor.current_left += (int16_t)(delta_left * accel_ratio);
        m_motor.current_right += (int16_t)(delta_right * accel_ratio);
    }

    /* 边界检查 */
    m_motor.current_left = CLAMP(m_motor.current_left, -MOTOR_SPEED_MAX, MOTOR_SPEED_MAX);
    m_motor.current_right = CLAMP(m_motor.current_right, -MOTOR_SPEED_MAX, MOTOR_SPEED_MAX);

    /* 驱动电机 */
    drive_motors(m_motor.current_left, m_motor.current_right);

    /* 检查是否完成 */
    if (++m_motor.step_index >= m_motor.step_total) {
        if (m_motor.auto_stop) {
            m_motor.stop_timer = now;
            m_motor.state = MOTOR_STATE_STOPPING;
        } else {
            m_motor.state = MOTOR_STATE_IDLE;
        }
        motor_sleep();
        LOG_INF("Movement completed");
    }
}

/* 新增停止处理 */
static void handle_auto_stop(void) {
    uint32_t now = k_uptime_get();
    
    // 确保有足够的停止时间
    if (now - m_motor.stop_timer >= MOTOR_UPDATE_INTERVAL) {
        m_motor.current_left = 0;
        m_motor.current_right = 0;
        drive_motors(0, 0);
        m_motor.state = MOTOR_STATE_IDLE;
        LOG_INF("Auto stop completed");
    }
}

void motor_init(void) {
    // 初始化GPIO
    if (!device_is_ready(gpioa2.port)) {
        LOG_ERR("GPIO device not ready");
        return;
    }
    gpio_pin_configure_dt(&gpioa2, GPIO_OUTPUT_INACTIVE);

    user_nvs_read_motor_dirs(&dir_left_trun, &dir_right_trun);

    // 初始化控制结构
    memset(&m_motor, 0, sizeof(m_motor));
    m_motor.state = MOTOR_STATE_IDLE;
    m_motor.last_update = k_uptime_get();
    
    // 生成加速曲线
    generate_accel_table();
    
    LOG_INF("Motor controller initialized");
}

void motor_move_smooth(int16_t left, int16_t right, uint16_t duration_ms) {
    motor_move_smooth_ex(left, right, duration_ms, true);
}

/* 新增函数实现 */
void motor_move_smooth_ex(int16_t left, int16_t right, uint16_t duration_ms, bool auto_stop) 
{
    // if (m_motor.state == MOTOR_STATE_ESTOP) return;
    motor_wakeup();

    // 设置目标参数
    m_motor.target_left = CLAMP(left, -MOTOR_SPEED_MAX, MOTOR_SPEED_MAX);
    m_motor.target_right = CLAMP(right, -MOTOR_SPEED_MAX, MOTOR_SPEED_MAX);
    m_motor.step_total = MAX(duration_ms / MOTOR_UPDATE_INTERVAL, 1);
    m_motor.step_index = 0;
    m_motor.state = MOTOR_STATE_MOVING;
    m_motor.last_update = k_uptime_get();
    m_motor.auto_stop = auto_stop;
    
    if (duration_ms == 0) {
        // 立即设置
        m_motor.current_left = m_motor.target_left;
        m_motor.current_right = m_motor.target_right;
        drive_motors(m_motor.current_left, m_motor.current_right);
        m_motor.state = MOTOR_STATE_IDLE;
    }
    
    LOG_INF("Move smooth to L:%d R:%d in %dms, auto_stop:%d", 
           left, right, duration_ms, auto_stop);
}
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

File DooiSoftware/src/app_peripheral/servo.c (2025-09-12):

/*
 * Copyright (c) 2016 Intel Corporation
 *
 * SPDX-License-Identifier: Apache-2.0
 */

#include <zephyr/kernel.h>
#include <zephyr/device.h>
#include <zephyr/drivers/gpio.h>
#include <zephyr/drivers/pwm.h>
#include <zephyr/logging/log.h>
LOG_MODULE_REGISTER(servo, LOG_LEVEL_INF);
#include <string.h>
#include <stdlib.h>
#include "servo.h"
#include "nvs.h"

/* PWM通道定义 */
static const struct pwm_dt_spec servos[] = {
    PWM_DT_SPEC_GET(DT_ALIAS(pwm1_servo)),  // 舵机1（左）
    PWM_DT_SPEC_GET(DT_ALIAS(pwm3_servo)),  // 舵机2（右）
};

#define GPIOA_3_NODE_D DT_ALIAS(motor_ctrl)
static const struct gpio_dt_spec gpio_exd3 = GPIO_DT_SPEC_GET(GPIOA_3_NODE_D, gpios);

#define GPIOD_6_NODE_D DT_ALIAS(motor_ctrl2)
static const struct gpio_dt_spec gpio_exd6 = GPIO_DT_SPEC_GET(GPIOD_6_NODE_D, gpios);

/* 可选的脉宽偏移校准 */
#define PWM_OFFSET  50000
int servo1_offset = 0;
int servo2_offset = 0;

/* 舵机参数 */
#define PWM_PERIOD_NS     20000000   // 20ms周期(50Hz)
#define MIN_PULSE_NS       500000    // 0.5ms(0度)
#define MAX_PULSE_NS      2500000    // 2.5ms(180度)
#define ANGLE_RANGE          180     // 角度范围

/* 运动学参数（按实际舵机调整）-----------------------------------------
 * 典型小舵机(如SG90)约 0.12~0.20s / 60°。
 * 下面给出一个保守默认：0.20s/60° => 3.333ms/°
 * 建议实机标定：把 SERVO_60DEG_MS 改成你的舵机真实值。
 */
#ifndef SERVO_60DEG_MS
#define SERVO_60DEG_MS 200u  // 200ms 走 60°
#endif
#define SERVO_MS_PER_DEG ((float)SERVO_60DEG_MS / 60.0f)
/* 运动完成后的静止余量，避免临界点提前断电 */
#ifndef SERVO_SETTLE_MS
#define SERVO_SETTLE_MS 30u
#endif
/* -------------------------------------------------------------------- */

/* 舵机动作控制结构（基于角度位移的时长估算） */
typedef struct {
    /* 运动学估算 */
    uint32_t start_ms;          // 本次运动起始时间（ms）
    uint32_t need_ms;           // 预计需要的运动时长（ms）——两舵机取最大
    uint16_t settle_ms;         // 额外静止余量（ms）

    /* 角度状态（逻辑角度，0~180） */
    int current_angle[2];       // 记录逻辑“当前角度”（软件侧）
    int target_angle[2];        // 记录本次目标角度

    bool moving;                // 正在运动标志
    bool update_needed;         // 需要更新标志（供调试，可不必）
} servo_control_t;

static servo_control_t m_servo;


void servo_enable(void) {
    gpio_pin_configure_dt(&gpio_exd3, GPIO_OUTPUT_LOW);
    gpio_pin_configure_dt(&gpio_exd6, GPIO_OUTPUT_LOW);
}

void servo_disable(void) {
    gpio_pin_configure_dt(&gpio_exd3, GPIO_OUTPUT_HIGH);
    gpio_pin_configure_dt(&gpio_exd6, GPIO_OUTPUT_HIGH);
}

/* 将角度转换为PWM脉冲宽度 */
static uint32_t angle_to_pulse(int angle)
{
    angle = CLAMP(angle, 0, ANGLE_RANGE);   /* 限制角度范围 */
    return MIN_PULSE_NS + (angle * (MAX_PULSE_NS - MIN_PULSE_NS)) / ANGLE_RANGE;
}

/* 立即更新舵机角度到目标 */
static void apply_angle(servo_select_t servo, int angle)
{
    uint32_t pulse_ns = 0;

    switch (servo) {
    case SERVO_LEFT:
        pulse_ns = angle_to_pulse(angle) + servo1_offset;
        pwm_set_pulse_dt(&servos[0], pulse_ns);
        break;

    case SERVO_RIGHT:
        pulse_ns = angle_to_pulse(180 - angle) + servo2_offset;
        pwm_set_pulse_dt(&servos[1], pulse_ns);
        break;

    case SERVO_BOTH:
        pulse_ns = angle_to_pulse(angle) + servo1_offset;
        pwm_set_pulse_dt(&servos[0], pulse_ns);
        pulse_ns = angle_to_pulse(180 - angle) + servo2_offset;
        pwm_set_pulse_dt(&servos[1], pulse_ns);
        break;
    }
}

/* 估算两角度间需要的时长（ms） */
static inline uint32_t estimate_ms_for_delta(int from_deg, int to_deg)
{
    int delta = abs(to_deg - from_deg);
    float ms = (float)delta * SERVO_MS_PER_DEG;
    /* 向上取整，保证不断电过早 */
    uint32_t ms_i = (uint32_t)ms;
    if ((float)ms_i < ms) { ms_i++; }
    return ms_i;
}

/* 统一计算一次动作需要的最长时间 */
static uint32_t compute_motion_time_ms(void)
{
    uint32_t ms_left  = estimate_ms_for_delta(m_servo.current_angle[0], m_servo.target_angle[0]);
    uint32_t ms_right = estimate_ms_for_delta(m_servo.current_angle[1], m_servo.target_angle[1]);
    uint32_t ms_need  = (ms_left > ms_right) ? ms_left : ms_right;

    /* 给点余量，叠加 settle */
    ms_need += m_servo.settle_ms;
    return ms_need;
}

void servo_init(void)
{
    /* 检查PWM设备是否就绪 */
    for (int i = 0; i < ARRAY_SIZE(servos); i++) {
        if (!device_is_ready(servos[i].dev)) {
            LOG_ERR("PWM device %d not ready", i);
            return;
        }
    }
    
    user_nvs_read_servo_offsets(&servo1_offset, &servo2_offset);

    servo_enable();

    memset(&m_servo, 0, sizeof(m_servo));
    m_servo.settle_ms = SERVO_SETTLE_MS;

    /* 初始角度假定 90°（软件状态与实际输出对齐） */
    m_servo.current_angle[0] = 0;
    m_servo.current_angle[1] = 0;
    m_servo.target_angle[0]  = 90;
    m_servo.target_angle[1]  = 90;
    m_servo.moving = false;

    servo_set_angle(SERVO_BOTH, 90);
}

void servo_set_angle(servo_select_t servo, int angle)
{
    angle = CLAMP(angle, 0, ANGLE_RANGE);

    /* 更新目标角度 */
    switch (servo) {
    case SERVO_LEFT:
        m_servo.target_angle[0] = angle;
        break;
    case SERVO_RIGHT:
        m_servo.target_angle[1] = angle;
        break;
    case SERVO_BOTH:
        m_servo.target_angle[0] = angle;
        m_servo.target_angle[1] = angle;
        break;
    }

    /* 立即输出 PWM 到目标（让舵机自行跑过去） */
    servo_enable();
    apply_angle(servo, angle);

    /* 重新估算动作时长（两舵机取最大）并启动计时 */
    m_servo.need_ms  = compute_motion_time_ms();
    m_servo.start_ms = k_uptime_get_32();
    m_servo.moving   = true;
    m_servo.update_needed = true;

    // LOG_DBG("servo_set_angle: L %d->%d, R %d->%d, need=%ums",
    //         m_servo.current_angle[0], m_servo.target_angle[0],
    //         m_servo.current_angle[1], m_servo.target_angle[1],
    //         m_servo.need_ms);
}

void servo_process(void)
{
    if (!m_servo.moving) {
        return;
    }

    uint32_t now = k_uptime_get_32();
    uint32_t elapsed = now - m_servo.start_ms;

    if (elapsed >= m_servo.need_ms) {
        /* 认为已到位：更新软件侧当前角度、断电省能 */
        m_servo.current_angle[0] = m_servo.target_angle[0];
        m_servo.current_angle[1] = m_servo.target_angle[1];

        servo_disable();
        m_servo.moving = false;
        m_servo.update_needed = false;
    }
}

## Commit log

2025-08-30 beta v1.1; 新增全新眼睛模块
2025-09-04 1、修复眼睛模块bug；2、优化
2025-09-07 beta v1.2; 1、优化动作序列 2、修复部分bug
    [action_sequences.c, app_music_ctrl.c, app_peripherals.c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]
2025-09-07 add:同步3d模型以及材料
    [BOM_DooiRobot V1.4.xlsx, DooiRobot复刻材料-电子配件及螺丝、工具和辅材 V1.7.xlsx, FDM_body_head.stl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]
2025-09-12 V1.3; add:nvs存储[舵机偏移、麦克风增益、对话模式、电机方向]; 优化唤醒词
